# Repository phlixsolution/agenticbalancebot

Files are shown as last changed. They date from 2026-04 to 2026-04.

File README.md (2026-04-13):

# BalanceBot

A two-wheeled self-balancing robot (inverted pendulum) built on an **Arduino Nano 33 IoT** with a **Nano Motor Carrier**.

<p align="center">
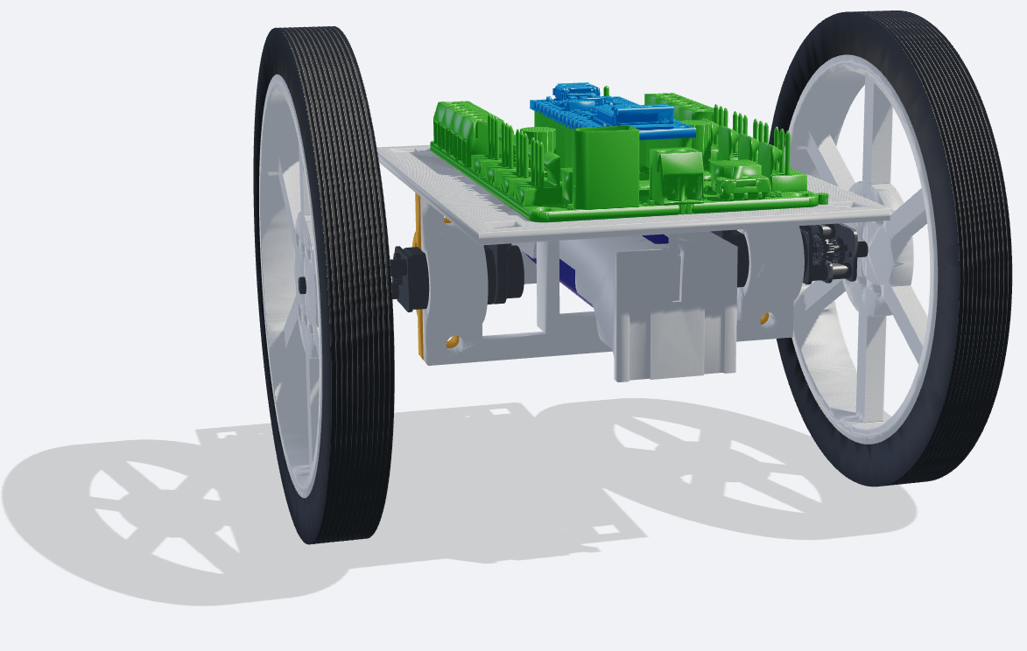
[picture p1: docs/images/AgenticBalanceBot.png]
BalanceBot CAD Assembly
  
</p>

The motivation behind this project is to develop a fully open-source robot from the existing components of the Arduino Engineering Kit Rev2. This allows interested owners of the kit to take the next step and gain a sustainable, license-independent engineering solution. Starting from these components, all necessary development steps and following design decisions are explained comprehensible in the documentation and provided in this repo. To keep the development effort manageable while leveraging the latest technology, [Agentic Supremacy](https://github.com/5omeOtherGuy/claude-skills-deploy) was developed and applied for this project.

The project follows a structured commissioning approach: each hardware subsystem is characterised and validated before the control loop is tuned.

## Hardware

| Component | Detail |
|---|---|
| MCU | Arduino Nano 33 IoT (SAMD21, WiFi/BLE) |
| Motor driver | Arduino Nano Motor Carrier |
| IMU | BNO055 (9-DOF, on-chip fusion) |
| Motors | 2 x micro gear motors, 100:1 ratio |
| Encoders | 2 x magnetic, 1200 counts/rev |
| Frame | Custom design (FreeCAD) |

## Repository layout

```
Balancebot_code/
  src/balance/          Modular firmware (active development)
  src/balance.cpp       balance_v1 — monolithic reference (read-only)
  src/tests/            Test sketches (carrier_timing, imu_latency, deadzone_id)
  python/               acquire → process → analyze data pipeline
  docs/                 commissioning_plan, sign_conventions, system_model
  messungen/            Measurement data (results tracked in repo)

CAD_BalanceBot/         FreeCAD assembly, STEP files, CoM analysis

docs/adr/               Architecture Decision Records (ADR-0001 … 0007)
Knowledg/               Physics derivations and explanations
```

## Firmware environments

Built with [PlatformIO](https://platformio.org/). Each environment compiles a different firmware:

| Environment | Purpose |
|---|---|
| `balance` | Modular control loop (active development) |
| `balance_v1` | Original monolithic firmware (reference) |
| `carrier_timing` | I2C timing characterisation |
| `imu_latency` | BNO055 read latency measurement |
| `deadzone_id` | Motor deadzone identification |

```bash
pio run -e balance -t upload     # flash
pio device monitor               # serial monitor
```

## Data pipeline

A three-stage Python pipeline for measurement acquisition and analysis:

```bash
python python/acquire.py                    # record serial data
python python/process.py <raw_file.csv>     # validate and compute derived signals
python python/analyze.py <proc_file.csv>    # generate plots
```

## Commissioning phases

The robot is brought up in phases — each phase validates assumptions the next one depends on. See [`commissioning_plan.md`](Balancebot_code/docs/commissioning_plan.md) for details.

| Phase | Goal | Status |
|---|---|---|
| 0 | Hardware verification | pending |
| 1 | Motor Carrier I2C timing | pending |
| 2 | BNO055 mode decision | pending |
| 3 | Deadzone identification | pending |
| 4 | Centre-of-gravity measurement | pending |
| 5 | System model | pending |
| 6 | First balance attempt (PD) | pending |
| 7 | Position controller | pending |

## Key design decisions

Documented as [Architecture Decision Records](docs/adr/README.md):

- **ADR-0001** Modular firmware layout supersedes balance_v1
- **ADR-0003** Motor duty hard-capped at 45 % (driver current limit)
- **ADR-0004** Three-stage Python pipeline supersedes standalone scripts
- **ADR-0005** PlatformIO as build system
- **ADR-0006** Control loop fixed at 10 ms (100 Hz)

## Getting started

### Prerequisites

- [PlatformIO CLI](https://docs.platformio.org/en/latest/core/installation.html)
- Python 3.12+ with dependencies: `pip install -r Balancebot_code/python/requirements.txt`
- Arduino Nano 33 IoT connected via USB

### Build and flash

```bash
cd Balancebot_code
pio run -e balance -t upload
```

### Lint

```bash
make lint    # runs ruff on the Python pipeline
```

## License

This project is developed as a university/hobby project. No license has been chosen yet.

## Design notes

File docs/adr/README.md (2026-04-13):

# Architecture Decision Records

Decisions that shape this project, captured as they happen.
New ADRs go in `docs/adr/NNNN-slug.md` and are indexed here.

| ADR | Title | Status | Date |
|-----|---|---|---|
| [0001](0001-modular-firmware-layout.md) | Modular firmware layout supersedes balance_v1 | accepted | 2026-04-13 |
| [0002](0002-messungen-storage-split.md) | Measurement data split between NextCloud and git | accepted | 2026-04-13 |
| [0003](0003-max-duty-45-percent.md) | Motor duty cycle hard-capped at 45% | accepted | 2026-04-13 |
| [0004](0004-three-stage-python-pipeline.md) | Three-stage Python pipeline supersedes standalone scripts | accepted | 2026-04-13 |
| [0005](0005-platformio-build-system.md) | PlatformIO as the build and upload system | accepted | 2026-04-13 |
| [0006](0006-control-loop-period-10ms.md) | Control loop period fixed at 10 ms (100 Hz) | accepted | 2026-04-13 |
| [0007](0007-ruff-python-linter.md) | ruff as the Python linter for the data pipeline | accepted | 2026-04-13 |

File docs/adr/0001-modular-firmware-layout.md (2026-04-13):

---
id: 0001
title: Modular firmware layout supersedes balance_v1
status: accepted
date: 2026-04-13
deciders: [both collaborators]
tags: [firmware, architecture]
---

# ADR-0001: Modular firmware layout supersedes balance_v1

## Context

The first working firmware, `Balancebot_code/src/balance.cpp` ("balance_v1"), is a
single 156-line file containing IMU setup, motor control, PID math, serial
logging, and the main loop. It proved the hardware works: the BNO055 reads,
the Motor Carrier drives, encoders count, and a basic PID compiles and runs.

As we move from "does anything work" to the commissioning phases in
`docs/commissioning_plan.md`, several limits of the monolithic file started
to hurt:

- **No unit boundaries.** Phase 3 (deadzone identification) and Phase 6
  (first balance attempt) need to swap controllers and log formats without
  touching IMU or motor code. In v1 every change touches the same file.
- **No test sketches can share code.** `src/tests/` (carrier_timing,
  imu_latency, deadzone_id) would either duplicate v1's driver code or
  include the whole file. Neither is acceptable.
- **Hardware-critical parameters are scattered.** `MAX_DUTY`,
  `DEADZONE_DUTY`, `FALLEN_ANGLE_DEG`, and the PID gains need one canonical
  location so CLAUDE.md's "ask before changing" list maps to real lines.
- **No explicit state machine.** v1 is always running; there is no IDLE,
  no FALLEN recovery, no E-STOP. For Phase 6+ with the wheels on the ground
  this is unsafe.

Alternatives considered:

1. **Keep extending `balance.cpp`.** Rejected — every added concern makes
   the next change harder, and the tuning phases will add many concerns.
2. **Rewrite as a single new monolithic file.** Rejected — same problem,
   just with newer code.
3. **Split into modules with a state machine and a central config header.**
   Chosen.

## Decision

`Balancebot_code/src/balance/` is the active firmware. It is organized as:

| Module | Responsibility |
|---|---|
| `config.h` | All hardware-critical constants (single source of truth) |
| `imu.{h,cpp}` | BNO055 init, read, angle extraction |
| `motor.{h,cpp}` | Motor Carrier wrapper, duty clamping, deadzone compensation |
| `encoder.{h,cpp}` | Encoder read and position tracking |
| `pid.{h,cpp}` | PID with anti-windup |
| `logger.{h,cpp}` | CSV serial output |
| `state_machine.h` | States INIT → CALIBRATING → IDLE → BALANCING → FALLEN → E_STOP, plus transition logic. Header-only (no `.cpp`) since it is enums + inline helpers. |
| `main.cpp` | Setup, loop, serial command dispatch |

`balance.cpp` (v1) and `src/*.cpp.bak` files are **frozen reference
artifacts**. They are kept in the repo but not edited. CLAUDE.md's
"What not to touch" section enforces this.

New work — deadzone compensation, cascade controllers, tuning logging —
lands in `src/balance/` only.

## Consequences

**Positive**
- Test sketches in `src/tests/` can `#include` individual modules instead
  of duplicating driver code.
- The state machine makes safety transitions (FALLEN cutoff, E-STOP)
  explicit and reviewable.
- `config.h` gives CLAUDE.md's parameter table exact line references,
  so "ask before changing" is enforceable in review.
- Per-module files stay small enough to review as units (largest is
  `main.cpp` at ~294 lines).

**Negative**
- Two firmware trees coexist. A reader unfamiliar with the history might
  start from `balance.cpp` by accident. Mitigated by CLAUDE.md and by this
  ADR.
- Slightly more boilerplate (headers, includes) than a single file.

**Neutral**
- v1's serial log format (`millis,pitch,p,i,d,pid_out,duty,position`) is
  preserved by `logger.cpp` so existing `messungen/` recordings remain
  comparable.

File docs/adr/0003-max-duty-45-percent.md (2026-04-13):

---
id: 0003
title: Motor duty cycle hard-capped at 45%
status: accepted
date: 2026-04-13
deciders: [both collaborators]
tags: [firmware, hardware, safety]
---

# ADR-0003: Motor duty cycle hard-capped at 45%

## Context

The Arduino Motor Carrier's motor driver is rated for a continuous current
of **500 mA**. Measured stall current of the motors is **1.03 A** (see
`config.h` line 48: `// Motorstall: 1.03 A, Treibergrenze: 0.50 A`).

At 100% PWM duty the motors can draw their full stall current, which is
roughly 2× the driver's rating. Sustained overcurrent destroys the driver.

The PID output is unbounded by design (integral wind-up and large angle
errors can push it well above 100). Without a hard cap in the motor layer,
a transient or tuning mistake passes a destructive command directly to the
hardware.

The cap must be set low enough to keep current within the driver rating
under worst-case (stall) conditions, while leaving enough authority for
the balance controller to be effective.

At 45% duty and the measured stall current of 1.03 A:

```
I_stall_at_45% ≈ 0.45 × 1.03 A ≈ 0.46 A  <  0.50 A rated
```

This gives a small but real margin without requiring a precise motor
characterization.

## Decision

`MAX_DUTY = 45` in `config.h`. The motor layer clamps every duty command
to `[-MAX_DUTY, +MAX_DUTY]` before writing to the Motor Carrier.

This value must not be raised without either:
- measuring that the chosen duty does not produce sustained overcurrent, or
- replacing the motor driver with one rated for higher current.

## Consequences

**Positive**
- Driver is protected during all commissioning phases, including Phase 6
  where large PID transients are expected during the first balance attempts.
- A tuning mistake that saturates the PID output does not damage hardware.

**Negative**
- Limits peak torque and top speed. If the balance controller requires
  more authority (e.g. recovering from a large disturbance), 45% may be
  insufficient. This will become apparent during Phase 6 testing.
- If the motors are lightly loaded (wheels off ground), 45% may still
  produce audible coil whine or thermal stress at sustained stall — the cap
  does not replace the stall-detection timeout (`STALL_TIMEOUT_MS`).

**Neutral**
- `DEADZONE_DUTY = 10` (Phase 3 estimate) sits well below `MAX_DUTY`.
  The effective command range for balancing is therefore [10, 45]% in
  each direction, shrunk further by whatever deadzone compensation is
  added after Phase 3.

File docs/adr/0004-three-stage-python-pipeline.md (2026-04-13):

---
id: 0004
title: Three-stage Python pipeline supersedes standalone scripts
status: accepted
date: 2026-04-13
deciders: [both collaborators]
tags: [tooling, data, python]
---

# ADR-0004: Three-stage Python pipeline supersedes standalone scripts

## Context

The repository contains several older Python scripts that grew up
alongside the early hardware experiments:

```
python/serial_to_csv.py     — recorded serial data to a CSV
python/plot_serial.py       — plotted live data from the serial port
python/plot_csv.py          — plotted a previously saved CSV
python/plot_pid_live.py     — plotted PID signals live
python/plot_sensor_live.py  — plotted sensor signals live
```

Each script was self-contained: it handled its own serial reading,
its own CSV parsing, and its own plotting in a single file. That was
fine for early exploration, but as the commissioning phases grew more
systematic, three problems emerged:

1. **No reuse between scripts.** If the serial column format changed,
   every script needed updating independently. There was no shared
   definition of "what a valid balance CSV looks like."

2. **No way to re-run one step.** To replot with different axis ranges
   you had to re-run the whole script — including re-reading the serial
   port if the data wasn't already saved, or re-parsing and re-computing
   everything if it was.

3. **No validation layer.** Raw serial data can contain partial lines,
   glitches, and timing noise. None of the old scripts had a dedicated
   step that checked the data before plotting it. Bad rows silently
   produced bad plots.

## Decision

The active pipeline is `acquire.py → process.py → analyze.py`.
Each stage has one job and a clear input/output contract:

| Stage | Input | Output | Job |
|---|---|---|---|
| `acquire.py` | Serial port | `messungen/raw/*.csv` | Read from the robot, write raw data, nothing else |
| `process.py` | raw CSV | `messungen/processed/*_proc.csv` | Validate rows, compute derived signals (dt, t_s, speed_rad_s, pos_diff, pid_out) |
| `analyze.py` | processed CSV | `messungen/plots/*.png` | Plot — pitch, PID components, duty, position, deadzone curves |

Shared constants (serial port, baud rate, column names, directory paths)
live in `config.py` so each stage reads the same definitions.

The old standalone scripts are **frozen**. They are kept in the repo for
reference but must not be extended. New measurement work uses the pipeline.

### Why this split matters

Because the stages are separate programs with files as the handoff,
each one can be re-run independently:

- **Re-process** an old raw recording with a fixed `process.py` (e.g.
  after correcting a unit conversion) without re-recording.
- **Re-plot** with different parameters without re-processing.
- **Validate** data once in `process.py`; `analyze.py` can trust its input.
- **Test sketches** (`carrier_timing`, `imu_latency`, `deadzone_id`)
  use `acquire.py` with a `--mode` flag — no need for separate recording
  scripts per test type.

## Consequences

**Positive**
- Column names, directory paths, and validation rules are defined once
  in `config.py` and imported by all three stages.
- A change to the serial log format (e.g. adding a new signal) means
  updating `config.py` and `process.py` only — `analyze.py` receives
  the new column in the processed CSV automatically.
- The directory split in ADR-0002 (`raw/`, `processed/`, `plots/`) maps
  directly to the three stages. The two decisions reinforce each other.

**Negative**
- Three commands instead of one. For a quick look at live data, the old
  `plot_serial.py` was faster to invoke. `analyze.py --live` partially
  addresses this but is a secondary use case.
- The old scripts are still present in `python/`, which can confuse a
  new reader. Mitigated by this ADR and by CLAUDE.md's "What not to
  touch" section.

**Neutral**
- `process.py` currently computes a fixed set of derived signals. When
  new commissioning phases require new quantities (e.g. frequency-domain
  analysis for Phase 5), they are added to `process.py` as new columns
  — the pipeline structure does not need to change.

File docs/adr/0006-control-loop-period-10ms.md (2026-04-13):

---
id: 0006
title: Control loop period fixed at 10 ms (100 Hz)
status: accepted
date: 2026-04-13
deciders: [both collaborators]
tags: [firmware, control]
---

# ADR-0006: Control loop period fixed at 10 ms (100 Hz)

## Context

A self-balancing robot is an *inverted pendulum* — an inherently unstable
system that will fall over unless the controller corrects it fast enough.
"Fast enough" is determined by the physics: the natural falling speed of
the pendulum sets a minimum update rate below which no controller can
recover it.

Two hardware constraints bound the choice from above and below:

**Lower bound — physics and sensor bandwidth.**
A typical two-wheeled balancing robot with a centre-of-gravity height of
a few centimetres has a natural frequency in the range of a few Hz. The
controller must run significantly faster than the falling dynamics —
conventionally at least 10× the natural frequency — to have enough time
to react. 50–100 Hz is the standard range for robots of this size.

**Upper bound — IMU read time.**
The BNO055 IMU is read over I²C on every loop iteration. The `imu_latency`
test sketch (`src/tests/imu_latency/`) exists specifically to measure how
long a `getEvent()` call takes on this hardware. Early characterisation
showed the read takes roughly 2–3 ms. At a 5 ms period (200 Hz) the IMU
read alone would consume 40–60% of the budget; any overrun makes the loop
non-deterministic. The Arduino Nano 33 IoT also runs serial command
parsing, encoder updates, PID computation, and state machine transitions
in the same loop body.

Going below 10 ms risks overrunning the IMU read time, which was noted
explicitly in `config.h`:

```cpp
// 10 ms = 100 Hz. Nicht unter 10 ms gehen (Bandbreite des inversen Pendels)
constexpr unsigned long LOOP_PERIOD_MS = 10;
```

## Decision

`LOOP_PERIOD_MS = 10` (100 Hz). The loop uses a `millis()`-based
non-blocking scheduling pattern — if less than 10 ms has elapsed since
the last iteration, `loop()` returns immediately:

```cpp
if (elapsedMs < LOOP_PERIOD_MS) return;
float dt = (float)elapsedMs / 1000.0f;
```

`dt` is measured from actual elapsed time rather than the nominal 10 ms,
so small jitter in the Arduino's task scheduling does not accumulate as
a timing error in the PID integrator.

Timer interrupts were not used. The `millis()` pattern is simpler,
sufficient for this application, and avoids the complexity of interrupt
safety around shared state (IMU object, PID state, encoder counts).

## Consequences

**Positive**
- 10 ms leaves ~7–8 ms headroom after the IMU read for all other
  loop work — PID, encoder, serial, state machine.
- `dt` from actual elapsed time makes the PID integrator correct even
  if occasional loop iterations run slightly long.
- Simple to understand and debug: no interrupt handlers, no shared
  state concerns.

**Negative**
- `millis()` scheduling is cooperative, not preemptive. A blocking call
  anywhere in the loop (e.g. a slow I²C transaction) delays the next
  iteration. This is why all loop work must be non-blocking.
- 100 Hz may prove insufficient if the CoG height measurement (Phase 4)
  reveals a faster natural frequency than expected. In that case
  `LOOP_PERIOD_MS` can be lowered, but only after re-running
  `imu_latency` to confirm the new period is safe.

**Neutral**
- The `imu_latency` test sketch exists specifically to validate the upper
  bound assumption. It must be re-run before any change to `LOOP_PERIOD_MS`.

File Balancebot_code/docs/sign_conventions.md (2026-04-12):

# BalanceBot -- Vorzeichen-Konventionen

**Status:** Aus Diagnose-Sketch verifiziert (diagnose.cpp.bak)

---

## Koordinatensystem

Der Bot steht auf dem Boden, Fahrtrichtung ist "vorwärts" (definiert als Richtung, in die der USB-Port zeigt).

```
         ^ oben (Kippachse: positives Pitch = kippt nach hinten)
         |
    _____________________
   |                     |
   |   [USB]  [Motor C.] |  <-- Rückseite
   |_____________________|
         |
    === Achse ===
    (Wheel L)  (Wheel R)
         |
      Fahrtrichtung VORWÄRTS -->
```

---

## IMU (BNO055) -- Euler-Winkel

| Achse | event.orientation.x | Bedeutung |
|---|---|---|
| x | Heading [°] | Kompass-Nord (nicht genutzt) |
| y | Roll [°] | Seitwärtskippen |
| **z** | **Pitch [°]** | **Vorwärts/Rückwärts-Kippen** |

**Vorzeichenkonvention Pitch:**
- `pitch = 0°` → Bot steht aufrecht
- `pitch < 0°` → Bot kippt **vorwärts** (USB-Seite neigt sich nach vorne)
- `pitch > 0°` → Bot kippt **rückwärts**

*Verifiziert durch: Manuelles Kippen des Bots, Beobachtung des Serial-Outputs.*

---

## Motoren (M1 / M2)

| Motor | Lage | Positive Duty-Richtung |
|---|---|---|
| M1 | Rechts (Fahrtrichtung) | dreht **rückwärts** (wegen Einbaulage gespiegelt) |
| M2 | Links | dreht **vorwärts** |

**Ansteuerung für Vorwärtsfahrt:**
```
Vorwärts:  M1.setDuty(-duty)  +  M2.setDuty(+duty)   // duty > 0
Rückwärts: M1.setDuty(+duty)  +  M2.setDuty(-duty)   // duty > 0
```

In `motor.cpp` (`_applyToMotors`):
```cpp
m1Duty = -duty;   // invertiert wegen Einbaulage
m2Duty = +duty;
```

---

## Encoder

| Encoder | Motor | Vorwärtsfahrt |
|---|---|---|
| encoder1 | M1 (rechts) | **negativer** Count |
| encoder2 | M2 (links)  | **positiver** Count |

**Positions-Berechnung (Geradeausfahrt):**
```
position = (encoder2.getRawCount() - encoder1.getRawCount()) / 2
```
- Formel hebt die gegenläufige Montage auf
- Positiver Wert = Vorwärtsfahrt ✓

*Auflösung: 1200 Counts / Umdrehung → 0.236 mm / Count*

---

## Regelkreis -- Vorzeichen-Überprüfung

**KRITISCH:** Falsches Vorzeichen = instabiler Regelkreis (beschleunigt in Absturzrichtung)

Checkliste vor dem ersten Balancierversuch:

1. Bot nach **vorne** kippen → `pitch` wird **negativ** ✓/✗
2. Positiver Duty → Motor M2 dreht **vorwärts**, M1 dreht **rückwärts** ✓/✗
3. Bot nach vorne kippen → Regler berechnet **positiven** Fehler (`0 - negative_pitch > 0`) ✓/✗
4. Positiver Fehler → positiver PID-Ausgang → positive Duty → Bot fährt **vorwärts** ✓/✗
5. Vorwärtsfahren bei vorwärts-Kippen **stabilisiert** den Bot ✓/✗

**Negativer Feedback-Loop muss gelten:**
```
Vorwärts-Kippen → Fehler positiv → Duty positiv → vorwärts fahren → Kippen wird reduziert
```

Wenn der Bot beim Start sofort wegfährt: Vorzeichen von Kp umkehren!

---

## Zusammenfassung für Copy-Paste

```
pitch (event.orientation.z):  0=aufrecht, negativ=vorwärts-Kippen
Motor-Ansteuerung:             Vorwärts = M1(-), M2(+)
Encoder:                       Vorwärts = Enc1↓, Enc2↑
Position:                      (Enc2 - Enc1) / 2, positiv=vorwärts
PID-Fehler:                    setpoint(0) - pitch
Regelung:                      Fehler>0 → Duty>0 → vorwärts (korrigiert ✓)
```

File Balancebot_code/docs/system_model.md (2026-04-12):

# BalanceBot -- Systemmodell (Inverses Pendel auf Rädern)

**Status:** Platzhalter -- wird nach CoG-Messung (Phase 4) ausgefüllt

**Referenz:** Grasser et al. 2002, "JOE: A Mobile, Inverted Pendulum"

---

## Zustandsvektor

```
x = [θ, θ̇, x_pos, ẋ]
     │   │   │      └── Fahrgeschwindigkeit [m/s]
     │   │   └───────── Fahrposition [m]
     │   └───────────── Kippwinkelgeschwindigkeit [rad/s]
     └───────────────── Kippwinkel [rad] (0 = aufrecht)
```

---

## Systemparameter (aus Datenblatt / Messung)

| Symbol | Bedeutung | Wert | Quelle |
|---|---|---|---|
| m | Gesamtmasse [kg] | 0.204 | Gewogen |
| r | Radradius [m] | 0.045 | CAD |
| L | CoG-Höhe über Achse [m] | **TODO: Messen!** | Knife-Edge |
| J_w | Trägheit Rad [kg·m²] | TODO | Abschätzung |
| J_b | Trägheit Körper [kg·m²] | TODO | Abschätzung |
| R_a | Ankerwiderstand [Ω] | ≈ 11.65 | Datenblatt* |
| K_t | Drehmomentkonstante [N·m/A] | ≈ 0.2115 | Datenblatt* |
| K_e | Gegen-EMK-Konstante [V·s/rad] | = K_t | (BLDC-Näherung) |
| n | Getriebeübersetzung [-] | 100 | Datenblatt |

*Abschätzung aus Stallmoment und Stallstrom:  
  Kt = Stallmoment / (Stallstrom × n) = 0.0222 N·m / (1.03 A × 100) ≈ 0.000215 N·m/A (Motor)  
  Nach Getriebe: Kt_eff = Kt × n = 0.0215 N·m/A (Abtrieb)

*Ankerwiderstand: Ra = Nennspannung / Stallstrom = 12 V / 1.03 A ≈ 11.65 Ω

---

## Linearisiertes Zustandsraummodell

```
ẋ = A·x + B·u
y = C·x
```

Eingang: `u` = normierter Duty-Wert [-1, +1] (wird intern auf Spannung umgerechnet)  
Ausgang: `y` = [θ, x_pos] (IMU + Encoder)

Die A- und B-Matrizen werden nach Messung von L berechnet.

**TODO:** Python-Skript `python/system_id.py` erstellen:
1. Parameter eintragen
2. A, B aufstellen
3. Eigenwerte berechnen (offener Kreis: ein instabiler Pol erwartet!)
4. Steuerbarkeit prüfen: `control.ctrb(A, B)`
5. LQR-Design: `K, S, E = control.lqr(A, B, Q, R)`

---

## Natürliche Frequenz (Abschätzung)

Mit L ≈ 0.025 m (Schätzwert):

```
ω_n = sqrt(g / L) = sqrt(9.81 / 0.025) ≈ 19.8 rad/s ≈ 3.15 Hz
```

**Folgerung:** Controller-Bandbreite muss ≥ 3 × ω_n ≈ 10 Hz sein.  
Bei 100 Hz Abtastrate: 10 Samples pro Pendel-Schwingung → knapp ausreichend.  
→ **Abtastrate nicht unter 100 Hz reduzieren!**

---

## Nächste Schritte

- [ ] CoG-Höhe L messen (Knife-Edge-Test, siehe commissioning_plan.md Phase 4)
- [ ] Trägheitsmomente J_w und J_b abschätzen oder messen
- [ ] `python/system_id.py` schreiben
- [ ] LQR- oder Kaskadenregler-Entwurf durchführen
- [ ] Regler in `src/balance/main.cpp` einbauen

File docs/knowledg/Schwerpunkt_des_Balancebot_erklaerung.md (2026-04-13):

# Schwerpunkt (Center of Mass) — Bedeutung und Messmethoden

## Warum ist der Schwerpunkt so wichtig?

Der BalanceBot ist ein **inverses Pendel** — ein Stab, der auf seiner Spitze balanciert. Die Physik dahinter:

### 1. Kippmoment und Reaktionszeit

Je **hoeher** der CoM ueber der Radachse liegt, desto **langsamer** kippt der Bot. Das klingt paradox, ist aber das gleiche Prinzip wie beim Besenstiel-Balancieren: ein langer Stiel ist leichter zu balancieren als ein kurzer.

Physikalisch: Die Winkelfrequenz des inversen Pendels ist

```
omega_0 = sqrt(m * g * h / J)
```

| Symbol | Beschreibung | Einheit |
|---|---|---|
| omega_0 | Eigenfrequenz des inversen Pendels | rad/s |
| m | Gesamtmasse des Bots | kg |
| g | Erdbeschleunigung (9.81) | m/s^2 |
| h | Abstand CoM zur Radachse (vertikal) | m |
| J | Traegheitsmoment um die Radachse | kg*m^2 |

Ein hoeherer CoM erhoeht `h`, aber `J` waechst mit `h^2` — netto wird das System **traeger** und damit einfacher zu regeln.

#### Herleitung von omega_0

**Schritt 1 — Drehmoment durch Gravitation:**

Wenn der Bot um einen kleinen Winkel θ aus der Vertikalen kippt, erzeugt die Schwerkraft ein Drehmoment um die Radachse:

```
tau = m * g * h * sin(theta)
```

| Symbol | Beschreibung | Einheit |
|---|---|---|
| tau | Drehmoment um die Radachse | N*m |
| m | Gesamtmasse des Bots | kg |
| g | Erdbeschleunigung (9.81) | m/s^2 |
| h | Abstand CoM zur Radachse | m |
| theta | Kippwinkel aus der Vertikalen | rad |

**Schritt 2 — Newtons Rotationsgesetz:**

```
J * theta_ddot = tau
```

| Symbol | Beschreibung | Einheit |
|---|---|---|
| J | Traegheitsmoment um die Radachse | kg*m^2 |
| theta_ddot | Winkelbeschleunigung | rad/s^2 |
| tau | Drehmoment um die Radachse | N*m |

Eingesetzt:

```
J * theta_ddot = m * g * h * sin(theta)
```

**Schritt 3 — Linearisierung fuer kleine Winkel** (`sin(theta) ≈ theta`):

```
J * theta_ddot = m * g * h * theta
```

Umgestellt:

```
theta_ddot = (m * g * h / J) * theta
```

Das ist eine Differentialgleichung der Form `theta_ddot = omega_0^2 * theta`, mit:

```
omega_0 = sqrt(m * g * h / J)
```

> **Vorzeichen-Hinweis:** Beim *normalen* Pendel (CoM unter der Achse) steht ein Minus: `theta_ddot = -omega_0^2 * theta` → harmonische Schwingung, stabil. Beim *inversen* Pendel (CoM ueber der Achse) ist das Vorzeichen positiv → exponentielles Wachstum, instabil. Genau deshalb braucht der BalanceBot einen aktiven Regler.

#### Warum waechst J mit h²? — Steiner'scher Satz

Jeder Koerper hat ein Traegheitsmoment `J_cm` um seinen eigenen Schwerpunkt. Wird die Drehachse um eine Strecke `h` vom Schwerpunkt weg verschoben (hier: zur Radachse), gilt der **Steiner'sche Satz** (parallel axis theorem):

```
J = J_cm + m * h^2
```

| Symbol | Beschreibung | Einheit |
|---|---|---|
| J | Traegheitsmoment um die Radachse | kg*m^2 |
| J_cm | Traegheitsmoment um den eigenen Schwerpunkt | kg*m^2 |
| m | Gesamtmasse des Bots | kg |
| h | Abstand Schwerpunkt zur Radachse | m |

Der Term `m * h^2` waechst **quadratisch** mit dem Abstand `h`.

**Einsetzen in omega_0:**

```
omega_0 = sqrt(m * g * h / (J_cm + m * h^2))
```

Fuer den Fall, dass der Bot naeherungsweise eine Punktmasse im Abstand `h` ist (`J_cm` vernachlaessigbar klein gegenueber `m * h^2`):

```
omega_0 ≈ sqrt(m * g * h / (m * h^2))
         = sqrt(g / h)
```

**Zentrales Ergebnis:**

```
omega_0 ≈ sqrt(g / h)
```

- `h` verdoppeln → omega_0 sinkt um Faktor sqrt(2) → Bot kippt **langsamer**
- `h` halbieren → omega_0 steigt um Faktor sqrt(2) → Bot kippt **schneller**

Deshalb ist ein hoher Schwerpunkt einfacher zu balancieren — genau wie ein langer Besenstiel vs. ein kurzer Bleistift.

### 2. Y-Offset (vor/hinter der Achse)

Wenn der CoM nicht genau ueber der Radachse sitzt, muss der Regler **permanent gegensteuern**, um das statische Kippmoment auszugleichen. Das kostet Energie und reduziert den nutzbaren Regelbereich. Ideal: `CoM_Y = 0`.

### 3. X-Offset (links/rechts)

Ein seitlicher Versatz erzeugt eine **Kurvenfahrt-Tendenz** — der Bot driftet zur schweren Seite. Ideal: `CoM_X = 0`.

### 4. Regelparameter haengen direkt vom CoM ab

Die PID-Gains (`KP_ANGLE`, `KD_ANGLE` in `config.h`) werden auf Basis des Systemmodells berechnet. Das Modell braucht `COG_HEIGHT_M` — den Abstand des CoM zur Radachse. Ein falscher Wert fuehrt zu:

- Zu aggressive Gains -> Oszillation
- Zu schwache Gains -> Bot kippt um

---

## Messmethoden

### Methode 1: CAD-Berechnung (was `com_analysis.py` macht)

Das Skript berechnet den CoM aus den Volumina und Materialdichten aller Teile. Jedem Teil wird eine Materialdichte zugewiesen:

| Material | Dichte [g/cm^3] |
|---|---|
| PLA (Rahmen, Motorhalter, Radnaben) | 1.04 |
| FR4 / PCB (Motor Carrier, Arduino) | 1.85 |
| Batterie (18650 Li-Ion) | 2.70 - 2.75 |
| N20-Motor mit Getriebe | 4.50 |
| Radreifen (Gummi/TPU) | 1.15 |

**Vorteil:** Schnell, iterativ anpassbar, keine Hardware noetig.
**Nachteil:** Nur so genau wie die CAD-Modelle und die angenommenen Dichten.

Ausfuehrung:

```bash
cat com_analysis.py | /snap/bin/freecad --console
```

---

### Methode 2: Knife-Edge-Test (empfohlen zur Validierung)

Dies ist die in `commissioning_plan.md` Phase 4 vorgesehene Methode.

1. Bot komplett aufbauen (alle Teile montiert, Akku eingesetzt)
2. Den Bot auf eine **scharfe Kante** (Lineal, Metallschiene) legen
3. Die Kante verschieben, bis der Bot **genau im Gleichgewicht** liegt
4. Den Abstand der Kante zur Radachse messen -> das ist `h` (CoG height)
5. In **zwei Achsen** wiederholen (Y und X), um den vollstaendigen CoM zu bestimmen

```
        +----------+
        | BalanceBot|
        |    x CoM |
        +----+-----+
             |
    =========+=========  <- Knife edge (Gleichgewichtspunkt)
             |
         ----o----       <- Radachse
```

**Vorteil:** Einfach, keine Spezialgeraete noetig.
**Nachteil:** Nur eine Achse pro Messung.

---

### Methode 3: Aufhaenge-Methode (Plumb-Line)

1. An zwei verschiedenen Stellen am Bot je einen Haken oder Faden befestigen (nicht an der Achse)
2. Bot am ersten Punkt aufhaengen, frei pendeln lassen
3. Lotlinie entlang des Fadens auf dem Bot markieren
4. Bot am zweiten Punkt aufhaengen, erneut Lotlinie markieren
5. **Schnittpunkt der beiden Linien = CoM**
6. Vertikalen Abstand vom Schnittpunkt zur Radachse messen

**Vorteil:** Bestimmt den CoM in zwei Dimensionen gleichzeitig.
**Nachteil:** Markierungen muessen praezise sein.

---

### Methode 4: Zwei-Waagen-Methode (Two-Scale)

Den Bot flach auf zwei identische Kuechenwaagen legen, die in bekanntem Abstand stehen:

```
Waage A (zeigt F_A)         Waage B (zeigt F_B)
    |___________________________|
    <------- d_gesamt --------->
```

Berechnung:

```
L_cog_von_A = (F_B * d_gesamt) / (F_A + F_B)
```

| Symbol | Beschreibung | Einheit |
|---|---|---|
| L_cog_von_A | Abstand des CoM von Waage A | m |
| F_A | Gewichtskraft auf Waage A | N |
| F_B | Gewichtskraft auf Waage B | N |
| d_gesamt | Abstand zwischen den beiden Waagen | m |

Dies ergibt die horizontale CoM-Position. Den Bot 90 Grad drehen (aufrecht abstuetzen) und wiederholen, um die **vertikale CoM-Hoehe** zu bestimmen.

**Vorteil:** Rechnerisch genau, reproduzierbar.
**Nachteil:** Aufwendiger Aufbau, Bot muss stabil positioniert werden.

---

## Empfohlenes Vorgehen fuer den BalanceBot

1. **CAD-Berechnung** mit `com_analysis.py` -> erste Abschaetzung
2. **Knife-Edge-Test** (Phase 4) -> Validierung am echten Bot
3. Gemessenen Wert als `COG_HEIGHT_M` in `config.h` eintragen
4. Erst dann mit PID-Tuning (Phase 6) beginnen

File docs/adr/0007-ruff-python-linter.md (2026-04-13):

---
id: 0007
title: ruff as the Python linter for the data pipeline
status: accepted
date: 2026-04-13
deciders: [both collaborators]
tags: [python, tooling]
---

# ADR-0007: ruff as the Python linter for the data pipeline

## Context

The data pipeline (`acquire.py`, `process.py`, `analyze.py`) is shared
between two collaborators. Without a linter, style inconsistencies and
common mistakes (unused imports, wrong import order, outdated syntax)
accumulate silently and make the code harder to read over time.

The Python ecosystem has several established linting tools:
- **flake8** — style and error checking, widely used but slow, requires
  separate plugins for import sorting and syntax modernisation
- **pylint** — thorough but very slow and verbose; typically overkill for
  a small focused codebase
- **black** — formatter only, does not catch logical errors or imports
- **ruff** — covers style errors, warnings, undefined names, import
  sorting (`isort`), and syntax modernisation (`pyupgrade`) in a single
  tool; written in Rust and runs in milliseconds

For a two-person project running linting manually before commits, speed
and simplicity matter more than exhaustive analysis. Maintaining separate
tools for formatting, import sorting, and error checking adds friction
without proportional benefit.

## Decision

**ruff** is configured in `Balancebot_code/pyproject.toml` with the
following rule sets:

| Rule set | What it checks |
|---|---|
| `E`, `W` | pycodestyle style errors and warnings |
| `F` | pyflakes — undefined names, unused imports |
| `I` | import order (replaces isort) |
| `UP` | outdated Python syntax (replaces pyupgrade) |

`E501` (line too long) is suppressed globally — matplotlib and pandas
call chains make strict line limits impractical without hurting
readability.

The superseded standalone scripts (`plot_serial.py`, `serial_to_csv.py`,
`plot_csv.py`, `plot_pid_live.py`, `plot_sensor_live.py`) are excluded
from linting entirely (`ALL`). They are frozen reference artifacts
(ADR-0004); generating lint noise from them would obscure real issues
in the active pipeline.

Line length is set to 100 characters — a pragmatic middle ground between
the traditional 79 (PEP 8) and the unconstrained style of the pipeline's
data manipulation chains.

## Consequences

**Positive**
- One tool replaces flake8 + isort + pyupgrade. A single `ruff check`
  invocation covers all rule sets in under a second.
- Excluding the frozen scripts means lint output is signal only — every
  reported issue is in code that is actively maintained.
- `pyproject.toml` pins the rule sets and line length, so both
  collaborators get identical results regardless of ruff version.

**Negative**
- ruff does not auto-fix all violations (though `ruff check --fix`
  handles most `I` and `UP` rules). Some style errors still require
  manual correction.

**Neutral**
- ruff is not run as a commit hook by default. The Makefile's `lint`
  target (`make lint`) is the intended invocation point. Adding a
  pre-commit hook is possible but not required for a two-person project.

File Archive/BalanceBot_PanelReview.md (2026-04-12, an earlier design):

# Panel Review: BalanceBot
*Generated: 2026-04-10 | Reviewers: data-analyst, embedded-dev, engineer*

**Overall Verdict: NEEDS IMPROVEMENT**

The hardware is adequate and the toolchain is functional, but the project lacks the control engineering backbone (plant model, state definition, control architecture, safety strategy) needed before attempting closed-loop balancing. The motor driver current limit is a real but manageable constraint.

---

## Consensus

All three reviewers agree on the following:

- **The stall current / driver limit mismatch (1.03A vs. 500mA) must be addressed in software before any closed-loop balance attempt.** A duty cycle clamp at ~48% is the minimum viable protection. All three independently derived this figure.
- **No plant model exists yet — this blocks all principled controller design.** Trial-and-error tuning on this system risks repeated overcurrent events and driver damage.
- **Sign/coordinate conventions are undefined.** A single sign error inverts the feedback loop and the robot accelerates into the ground. This must be documented and verified before writing any control code.
- **IMU data is not logged.** The primary controlled variable (tilt angle) is absent from the CSV schema, making post-hoc analysis of balance behavior impossible.
- **Anti-windup is mandatory.** With the hard duty cap, integrator windup during saturation will cause slow reversal and falls. All three reviewers flagged this independently.
- **Sampling time jitter is uncharacterized.** No hardware timer drives the control loop — `loop()` with `millis()` checks produces jitter that can destabilize the controller.

---

## Domain-Specific Insights

### Data Analyst — Dead-time measurement before system identification

Before fitting any transfer function, the total loop delay (serial framing + task scheduling + filter group delay) must be measured. A 20-30ms unmodeled delay in a 10ms sampling system is not negligible and causes `curve_fit` to underestimate time constants. The fix: inject a known step, timestamp the command on the PC with `time.perf_counter()`, and measure the first non-zero response. Then fit a PT1+dead-time model.

### Embedded Developer — The ArduinoMotorCarrier library is a black box that must be characterized

Every control signal and sensor reading passes through I2C transactions to the ATSAMD11 co-processor. The latency, update rate, atomicity, and watchdog behavior of this communication path are unknown. A test sketch measuring round-trip times of `controller.ping()`, `encoder1.getRawCount()`, `M1.setDuty()`, and IMU reads (1000 iterations, log min/max/mean) is mandatory before trusting the library in a closed loop.

### Engineer — The system has ample torque margin but dynamic bandwidth is the real constraint

At the driver-limited torque (0.211 N·m total), the static torque margin is ~48:1 at 5° tilt — more than enough. The natural frequency of the inverted pendulum (with estimated L_cog = 25mm) is ~3.15 Hz, requiring a controller bandwidth of 10-15 Hz. At 100 Hz sampling, this gives only 7-10 samples per cycle — tight but workable. Do not reduce the sampling rate below 100 Hz.

---

## Critical Issues

| # | Issue | Raised by | Impact |
|---|---|---|---|
| 1 | **Motor stall current (1.03A) exceeds driver limit (500mA) — no software protection exists** | All three | Hardware damage or thermal shutdown during any significant balance correction. Duty clamp at 48% is mandatory. |
| 2 | **No hardware-timer-driven control loop** | Embedded, Engineer | Timing jitter from `loop()` + serial I/O + `controller.ping()` can destabilize the controller. 1-2ms jitter at 10ms sample = 10-20% variation. |
| 3 | **Motor Carrier communication path is uncharacterized** | Embedded | If `controller.ping()` or I2C transactions take 5ms on some calls, the 10ms budget is blown and the controller sees stale data. |

---

## Improvement Roadmap (unified)

| Priority | Improvement | Raised by | Actionable steps |
|---|---|---|---|
| **HIGH** | Implement duty limiting and stall detection | All three | `duty = constrain(duty, -48, +48)`. Add slew rate limit (max 20 units/sample). Stall detection: if `abs(duty) > 30 && abs(speed) < 5` for 500ms → E_STOP. |
| **HIGH** | Build linearized state-space model | Engineer, Data Analyst | Measure CoG height (knife-edge test). Extract motor params from datasheet (R_a ≈ 11.65Ω, K_t = 0.2115 N·m/A). Write the 4-state [θ, θ̇, x, ẋ] equations per Grasser et al. (2002). Verify open-loop eigenvalues. |
| **HIGH** | Characterize Motor Carrier communication | Embedded | Test sketch: 1000 iterations of each API call, log timing via `micros()`. Determine I2C bus speed, encoder atomicity, and `ping()` latency. |
| **HIGH** | Implement hardware-timer control loop | Embedded | Configure SAMD21 TC3 for 10ms ISR. Execute read→compute→actuate in the ISR or flag-driven highest-priority task. Verify with GPIO toggle. |
| **HIGH** | Add IMU data to log schema | Data Analyst, Embedded | Add `imu_angle_deg`, `imu_rate_dps` to the `Serial.println()` line. Cost: ~30 bytes/line at 100 Hz = 3 kB/s. |
| **HIGH** | Define and verify sign conventions | Engineer, Embedded | One-page diagram. Four test sketches: tilt forward → angle sign? Positive duty → encoder sign? Positive duty → wheel direction? Verify negative feedback loop product. |
| **HIGH** | Implement state machine | Embedded | States: INIT → CALIBRATING → IDLE → BALANCING → FALLEN → E_STOP. Transitions on tilt angle threshold, serial commands, overcurrent. Motors off in FALLEN and E_STOP. |
| **MEDIUM** | Implement anti-windup | Engineer, Data Analyst | Back-calculation: `e_aw = duty_clamped - duty_unclamped`, feed back to integrator with tracking gain `Kaw = 1/Ti`. |
| **MEDIUM** | Configure BNO055 for minimum latency | Engineer, Embedded | Set IMU mode (0x08), not NDOF. Disable magnetometer fusion. If latency still too high, implement complementary filter: `angle = 0.98*(angle + gyro*dt) + 0.02*accel_angle`. |
| **MEDIUM** | Split Python pipeline into acquire/process/analyze | Data Analyst | `acquire.py` (serial → raw CSV), `process.py` (validation + derived signals → Parquet), `analyze.py` (plots + fits). Add `config.py` and `requirements.txt`. |
| **MEDIUM** | Characterize and compensate motor dead zones | Engineer, Data Analyst | Ramp duty 0→100% slowly, log encoder velocity vs. duty. Implement piecewise linear feedforward per motor. |
| **MEDIUM** | Measure dead-time / transport delay | Data Analyst | Inject step from PC, timestamp with `time.perf_counter()`, measure first non-zero response. Fit PT1+dead-time model. |
| **MEDIUM** | Implement cascade control structure | Engineer | Inner loop: PD on tilt angle → duty. Outer loop: PI on position → tilt setpoint. Tune inner first (robot balances but drifts), then close outer. |
| **LOW** | Enable SAMD21 hardware watchdog | Embedded | WDT ~50ms timeout, fed only from control loop ISR. Catches I2C bus lockups. |
| **LOW** | Switch long-run storage to Parquet | Data Analyst | `df.to_parquet()` after validation. Keep raw CSV as archival input. |
| **LOW** | Report confidence intervals on all curve_fit results | Data Analyst | Compute `sigma = sqrt(diag(pcov))`, print 95% CI. Flag if CI width > 50% of nominal. |

---

## Research & Reference Projects

### Control Theory & Modeling

1. **Grasser, D'Arrigo, Colombi, Rufer — "JOE: A Mobile, Inverted Pendulum" (IEEE 2002)**
   Search: `Grasser D'Arrigo "JOE" inverted pendulum IEEE 2002`
   *Relevance:* The canonical reference for two-wheeled inverted pendulum state-space modeling. Provides the exact A and B matrices for BalanceBot's model.
   *What to look for:* State vector definition [θ, θ̇, x, ẋ], linearization procedure, LQR weight selection.

2. **Steve Brunton — Control Bootcamp (YouTube + GitHub)**
   Search: `Steve Brunton Control Bootcamp inverted pendulum`
   *Relevance:* LQR design for inverted pendulum with worked MATLAB examples. Directly applicable once the state-space model is built.
   *What to look for:* Controllability, LQR weight selection, observer design.

3. **Brian Douglas — Control Systems Lectures (YouTube / MATLAB Tech Talks)**
   Search: `Brian Douglas inverted pendulum state space`
   *Relevance:* Best video explanation of the complete state-space design flow from model to LQR to observer.
   *What to look for:* "What is LQR" and "What is a State Observer" videos.

4. **Franklin, Powell, Emami-Naeini — "Feedback Control of Dynamic Systems" (8th ed.)**
   *Relevance:* Chapter 7, Example 7.28 covers inverted pendulum LQR with explicit Q/R selection procedure.
   *What to look for:* Constraint-aware LQR weight tuning (R chosen so gains stay within actuator limits).

### Balancing Robot Implementations

5. **Brokking.net / YABR (Yet Another Balancing Robot)**
   URL: `http://www.brokking.net/yabr.html`
   *Relevance:* Complete Arduino-based balance bot with source code, PID tuning videos, complementary filter, dead zone compensation. Closest pedagogical match.
   *What to look for:* Incremental commissioning methodology (IMU alone → motors alone → combine).

6. **B-ROBOT / JJRobots EVO 2**
   URL: `https://jjrobots.com/b-robot-evo-2/`
   *Relevance:* Open-source Arduino balance bot with cascade PD/PI control, dead zone handling, and anti-windup.
   *What to look for:* Control architecture and practical tuning approach.

### Embedded Firmware Patterns

7. **ArduinoMotorCarrier Library Source Code**
   URL: `https://github.com/arduino-libraries/ArduinoMotorCarrier`
   *Relevance:* Mandatory reading. Reveals I2C transaction timing, co-processor protocol, BNO055 data path.
   *What to look for:* What each API call does at the I2C level. Whether BNO055 is routed through ATSAMD11 or direct I2C.

8. **FreeRTOS-SAMD21 Port**
   URL: `https://github.com/BriscoeTech/Arduino-FreeRTOS-SAMD21`
   *Relevance:* Solves control loop vs. serial I/O vs. safety scheduling with proper task priorities.
   *What to look for:* Task creation, binary semaphores for ISR-to-task signaling, stack sizing for 32KB SRAM.

9. **SimpleFOC Library (Arduino-FOC)**
   URL: `https://github.com/simplefoc/Arduino-FOC`
   *Relevance:* Excellent firmware architecture patterns (timer ISR, sensor/controller/actuator separation, serial commander) transferable to BalanceBot.
   *What to look for:* Timer ISR structure, SAMD21-specific timer configuration, command interface pattern.

10. **Madgwick AHRS Filter**
    URL: `https://github.com/arduino-libraries/MadgwickAHRS`
    *Relevance:* Fallback if BNO055's internal fusion has too much latency. Lightweight quaternion-based filter.
    *What to look for:* Integration with raw accel+gyro data, beta parameter tuning.

### Sensor & Driver References

11. **BNO055 Datasheet + Application Note BST-BNO055-AN007**
    Search: `BNO055 "fusion output data rate" IMU mode vs NDOF mode`
    *Relevance:* IMU mode gives lowest latency. NDOF magnetometer recalibration causes transient jumps — catastrophic for balancing.
    *What to look for:* Section 3.6 (Output Data Rates), operation mode 0x08 (IMU mode).

12. **TI Application Note SLVA249 — "Current Limiting in H-Bridge Motor Drivers"**
    *Relevance:* Duty cycle clamp derivation from motor model, thermal protection for H-bridges.
    *What to look for:* Software current limiting methodology, thermal derating curves.

### Python Analysis Tools

13. **Python Control Systems Library (python-control)**
    URL: `https://python-control.readthedocs.io`
    *Relevance:* Python equivalent of MATLAB's Control System Toolbox. Bode plots, root locus, step response, sisotool.
    *What to look for:* `control.tf()`, `control.step_response()`, `control.bode_plot()`.

14. **SIPPY — System Identification Package for Python**
    URL: `https://github.com/CPCLAB-UNIPI/SIPPY`
    *Relevance:* Proper prediction-error system identification (ARX, ARMAX, state-space) from measured I/O data.
    *What to look for:* State-space identification from step response CSV data.

15. **Phil's Lab (YouTube) — Complementary Filter and PID Tuning**
    Search: `Phil's Lab complementary filter IMU PID`
    *Relevance:* Practical video tutorials bridging textbook theory and embedded implementation, with real hardware.
    *What to look for:* Complementary filter, anti-windup, visual tuning methodology.

16. **TinyMPC — Model Predictive Control for Microcontrollers**
    URL: `https://github.com/TinyMPC/TinyMPC`
    *Relevance:* Future path if progressing beyond LQR. Lightweight MPC for Cortex-M with balance system examples.
    *What to look for:* Fixed-size matrix operations, no dynamic allocation, deterministic iteration count.

---

## Dissent

### BNO055 fusion vs. custom complementary filter

- **Engineer:** Try BNO055 internal IMU mode fusion first, fall back to complementary filter only if latency is measured to be too high.
- **Embedded Developer:** More skeptical — data likely routes through ATSAMD11 (unknown latency), prefers Madgwick/Mahony on SAMD21 from raw sensor data for guaranteed low latency.
- **Chair's recommendation:** Characterize the BNO055 path first (latency measurement). If total sensor latency exceeds ~15ms, switch to complementary or Madgwick filter on SAMD21. Don't build the fallback until proven necessary.

### PID cascade vs. LQR state feedback

- **Engineer:** Recommends building the state-space model and designing LQR — naturally handles coupled angle-position dynamics.
- **Data Analyst / Embedded Developer:** Implicitly assume a PID cascade structure (inner angle, outer position).
- **Chair's recommendation:** Build the state-space model regardless. Start with PD tilt controller for initial balance proof-of-concept, then choose between cascade PID and LQR based on comfort level. Both work; LQR is theoretically cleaner, cascade PID is easier to tune incrementally.

---

## Recommended Next Steps

1. **Start with safety:** Implement the duty clamp (48%) and stall detection. 2-3 hours, protects hardware for all subsequent work.
2. **Characterize the unknowns:** Run the Motor Carrier timing test and BNO055 latency measurement. Determines whether the current software stack is viable for 100 Hz control.
3. **Build the model:** Measure CoG height, compute state-space matrices, verify open-loop eigenvalues. Unlocks principled controller design.
4. **Extend logging:** Add IMU angle and rate to CSV. Split the Python pipeline. Every experiment from this point captures the full state.

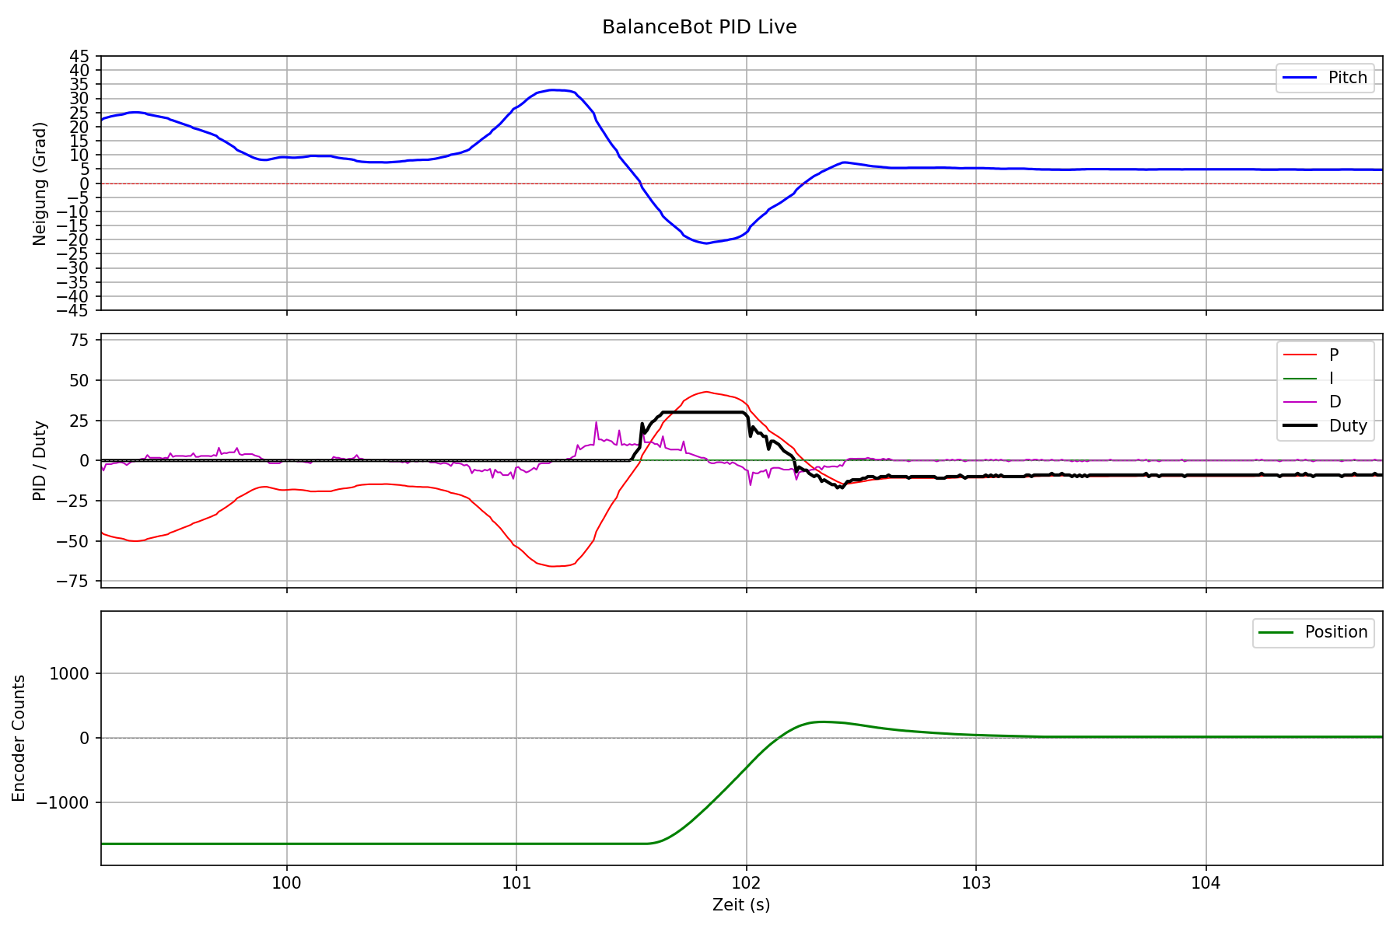
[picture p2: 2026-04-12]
Balancebot_code/messungen/pid_20260410_183701.png

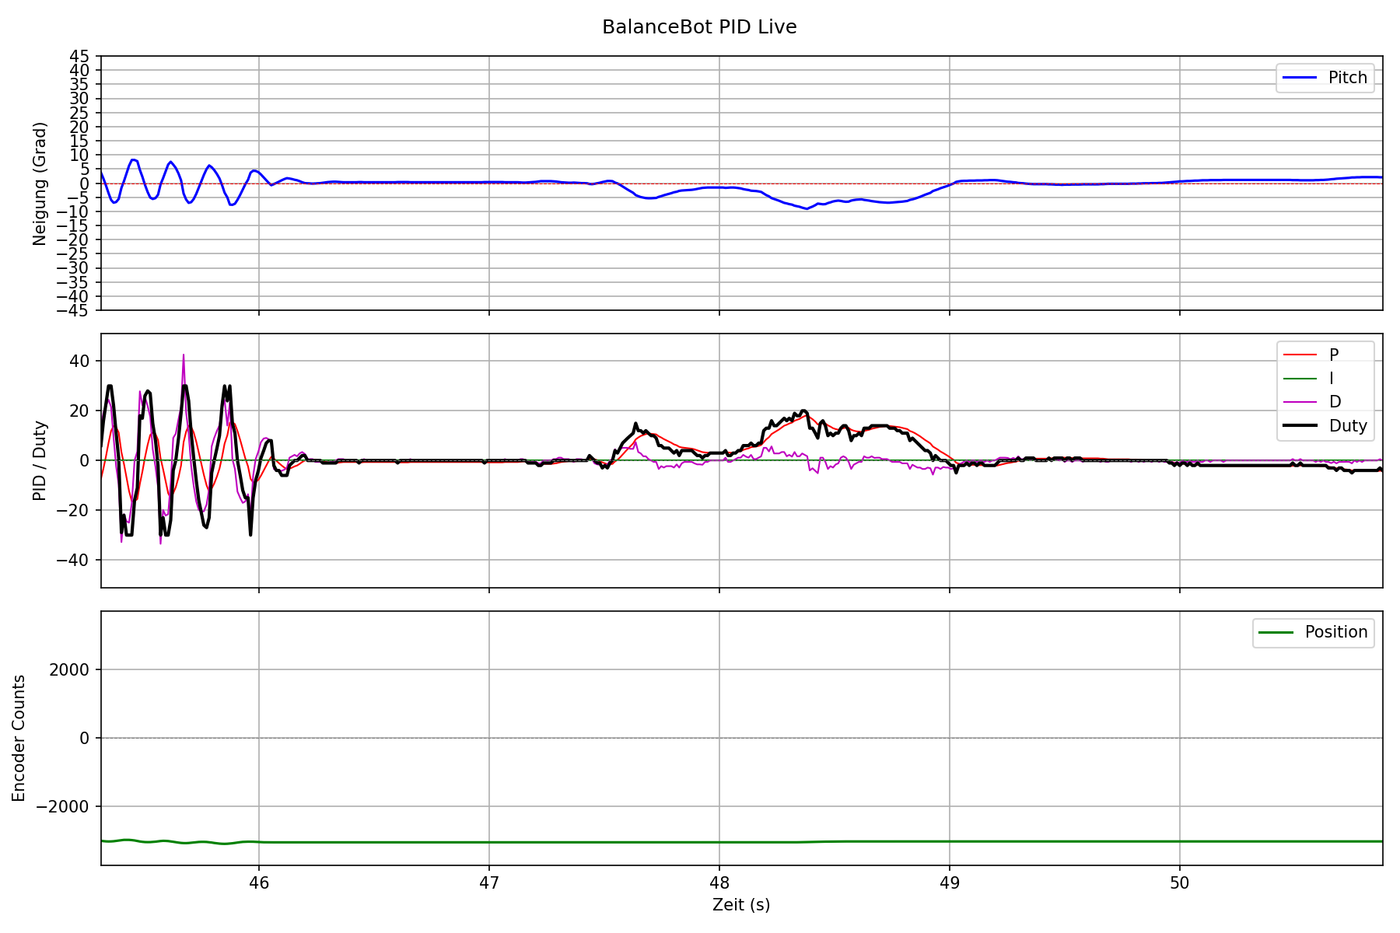
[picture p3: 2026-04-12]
Balancebot_code/messungen/pid_20260410_184142.png

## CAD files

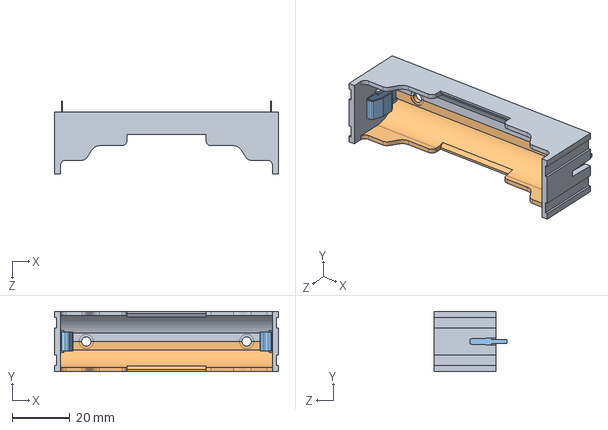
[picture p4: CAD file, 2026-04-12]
CAD_BalanceBot/User Library-18650 Full.STEP
77.6 x 20.8 x 25.5 mm
18650m_1
18650s_По умолчанию x 2

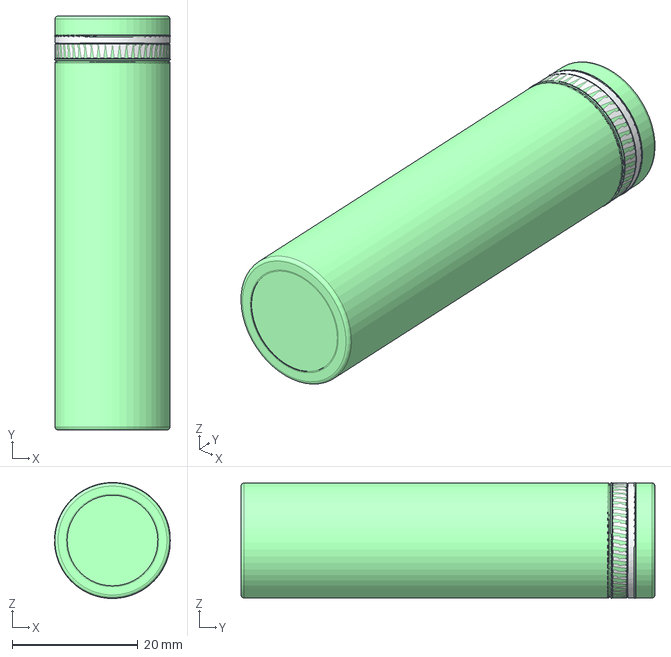
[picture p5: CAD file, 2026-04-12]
CAD_BalanceBot/Samsung INR18650-25R.stp
18.5 x 65.8 x 18.5 mm

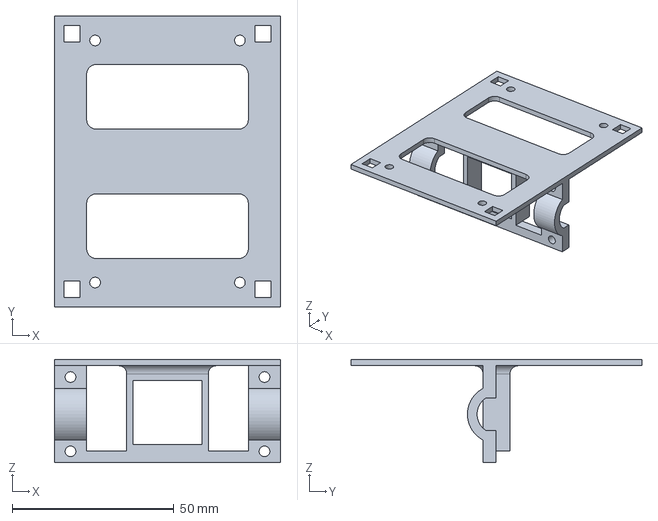
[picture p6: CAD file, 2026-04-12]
CAD_BalanceBot/botframe.FCStd
70.0 x 90.0 x 32.0 mm

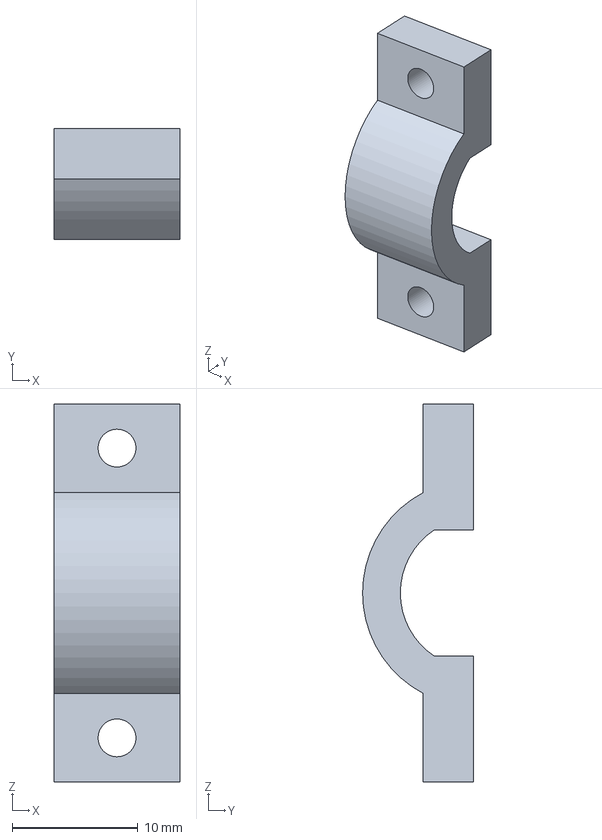
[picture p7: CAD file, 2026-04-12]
CAD_BalanceBot/motorhalter_lose.FCStd
10.0 x 8.80 x 30.0 mm

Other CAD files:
CAD_BalanceBot/Pololu_Wheel_90x10.FCStd
CAD_BalanceBot/Pololu 90mm Wheel.dwg

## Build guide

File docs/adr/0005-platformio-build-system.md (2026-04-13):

---
id: 0005
title: PlatformIO as the build and upload system
status: accepted
date: 2026-04-13
deciders: [both collaborators]
tags: [tooling, firmware, build]
---

# ADR-0005: PlatformIO as the build and upload system

## Context

Arduino firmware can be built and uploaded in several ways. The most
common starting point is the **Arduino IDE** — a graphical tool that
hides most of the build process. It works well for single-file sketches
but has significant limitations as a project grows:

- No support for a proper `src/` directory structure; all `.cpp` files
  must live in the sketch folder.
- Library management is global and per-machine, not per-project.
  Two collaborators can silently have different library versions installed.
- No CLI — building and uploading requires the GUI, making it harder
  to script or reproduce.
- No named build environments — switching between `balance_v1` and the
  modular `balance/` target, or between production firmware and test
  sketches, requires manual file swapping.

This project has five distinct firmware targets that need to coexist:
`balance_v1` (reference), `balance` (active development), and three
test sketches (`carrier_timing`, `imu_latency`, `deadzone_id`). Managing
these in the Arduino IDE would require five separate sketch folders with
duplicated library references.

## Decision

**PlatformIO** (`platformio.ini` at `Balancebot_code/`) is the build
and upload system for all firmware.

The configuration defines a shared `[common]` block (board, platform,
framework, baud rate, library dependencies) that all environments inherit.
Each environment overrides only `build_src_filter` to select its source:

| Environment | Source | Purpose |
|---|---|---|
| `balance_v1` | `src/balance.cpp` | Reference build — frozen |
| `balance` | `src/balance/` | Active modular firmware |
| `carrier_timing` | `src/tests/carrier_timing/` | Phase 1 test |
| `imu_latency` | `src/tests/imu_latency/` | Phase 2 test |
| `deadzone_id` | `src/tests/deadzone_id/` | Phase 3 test |

Library versions are pinned in `platformio.ini`:

```ini
lib_deps =
    adafruit/Adafruit BNO055@^1.6.1
    adafruit/Adafruit Unified Sensor@^1.1.14
    arduino-libraries/ArduinoMotorCarrier
```

Both collaborators build against the same versions regardless of what
is installed globally on their machines.

Common commands:
```bash
pio run -e balance -t upload   # build and flash active firmware
pio run -e balance_v1          # build reference (verify it still compiles)
pio device monitor             # open serial monitor at 115200 baud
```

## Consequences

**Positive**
- Library versions are locked in the repo. Both collaborators always
  build with identical dependencies.
- `build_src_filter` is the mechanism that enforces the firmware layout
  decision from ADR-0001: each environment compiles exactly one target,
  so `balance_v1` and `balance/` cannot accidentally include each other.
- Test sketches are first-class build targets — no file swapping needed
  to flash `carrier_timing` or `deadzone_id`.
- Builds and uploads are scriptable from the command line, which is
  required once we add CI or automated test runs.

**Negative**
- PlatformIO must be installed (`pip install platformio` or via the VS
  Code extension). A collaborator with only the Arduino IDE cannot build
  the project without installing it first.
- PlatformIO downloads board support packages and libraries on first
  use, which requires an internet connection and takes a few minutes.

**Neutral**
- The Arduino Nano 33 IoT board definition (`board = nano_33_iot`,
  `platform = atmelsam`) is specified once in `[common]` and inherited
  by all environments. Changing to a different board requires one line.

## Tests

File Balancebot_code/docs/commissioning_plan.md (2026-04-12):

# BalanceBot -- Inbetriebnahmeplan

**Prinzip:** Jede Phase erst abschließen bevor die nächste beginnt.  
**Sicherheit:** Bei jedem Motortest Räder in der Luft! Nur bei Phase 5+ frei stellen.

---

## Phase 0: Hardware-Verifikation (einmalig, ohne Code-Änderung)

Ziel: Sicherstellen dass alle Komponenten korrekt verdrahtet und funktionsfähig sind.

- [ ] Motor Carrier erkennt Arduino (rote LED blinkt, `controller.getFWVersion()` gibt Version aus)
- [ ] Beide Motoren laufen bei Duty=30 (motor_test → `pio run -e balance_v1 -t upload`)
- [ ] Beide Encoder zählen korrekt (encoder_test, Rad von Hand drehen)
- [ ] BNO055 liefert plausible Pitch-Werte (sensor_test, Bot kippen)
- [ ] Vorzeichen-Konventionen verifiziert (diagnose, siehe `docs/sign_conventions.md`)

---

## Phase 1: Motor Carrier Timing-Charakterisierung

Ziel: I2C-Timing aller API-Aufrufe messen.

```bash
pio run -e carrier_timing -t upload
python acquire.py --mode carrier
```

**Erfolgskriterium:** Summe aller Mean-Werte < 8000 µs (80% von 10 ms Budget)  
**Falls nicht erfüllt:** I2C-Takt erhöhen oder Aufrufe reduzieren

- [ ] `controller.ping()` latenz notiert: _______ µs
- [ ] `encoder1.getRawCount()` latenz: _______ µs
- [ ] `encoder2.getRawCount()` latenz: _______ µs
- [ ] `M1.setDuty()` latenz: _______ µs
- [ ] `bno.getEvent()` latenz (NDOF): _______ µs
- [ ] `bno.getEvent()` latenz (IMU-Modus): _______ µs
- [ ] Summe: _______ µs → Budget OK? ✓/✗

---

## Phase 2: BNO055 Modus-Entscheidung

Ziel: NDOF vs. IMU-Modus vergleichen, BNO055-Konfiguration festlegen.

```bash
pio run -e imu_latency -t upload
python acquire.py --mode imu > messungen/raw/imu_latency.csv
python analyze.py messungen/raw/imu_latency.csv --mode imu
```

**Entscheidungsregel:**
- Wenn `bno.getEvent()` Latenz < 5 ms **und** Kalibrierung stabil → NDOF-Modus OK
- Wenn Latenz > 5 ms **oder** Kalibrierungssprünge → IMU-Modus (0x08) verwenden
- Wenn IMU-Modus immer noch > 5 ms → Complementary Filter auf SAMD21 implementieren

- [ ] Entscheidung getroffen: _________________ (NDOF / IMU-Modus / Comp. Filter)
- [ ] `imu.cpp` entsprechend konfiguriert (TODO-Kommentar in imu.cpp)

---

## Phase 3: Totzone-Identifikation

Ziel: Minimal-Duty für Anlaufen beider Motoren messen.

```bash
pio run -e deadzone_id -t upload
python acquire.py --mode deadzone
python process.py messungen/raw/deadzone_*.csv --mode deadzone
python analyze.py messungen/processed/deadzone_*_proc.csv --mode deadzone
```

- [ ] Totzone M1 gemessen: _______ % Duty
- [ ] Totzone M2 gemessen: _______ % Duty
- [ ] `DEADZONE_DUTY` in `config.h` aktualisiert: _______

---

## Phase 4: CoG-Höhe messen (Knife-Edge-Test)

Ziel: Schwerpunkthöhe `COG_HEIGHT_M` für Systemmodell bestimmen.

**Methode:**
1. Bot auf eine schmale Kante (Lineal) legen
2. Kante verschieben bis Bot balanciert
3. Vertikalen Abstand der Kante von der Radachse messen
4. Das ist die CoG-Höhe über Achsmitte

- [ ] CoG-Höhe gemessen: _______ mm über Achsmitte
- [ ] `COG_HEIGHT_M` in `config.h` aktualisiert

---

## Phase 5: Systemmodell aufstellen

Ziel: Linearisiertes Zustandsraummodell des inversen Pendels.

Zustandsvektor: `[θ, θ̇, x, ẋ]` (Winkel, Winkelgeschwindigkeit, Position, Geschwindigkeit)

Referenz: Grasser et al. 2002 "JOE: A Mobile, Inverted Pendulum"

**Schritte:**
1. Motorparameter aus Datenblatt extrahieren (Ra ≈ 11.65 Ω, Kt aus Stallmoment)
2. Trägheitsmomente schätzen (Masse × CoG² als Näherung)
3. A- und B-Matrizen aufstellen
4. Eigenwerte des offenen Kreises berechnen (Python: `numpy.linalg.eig`)
5. Steuerbarkeit prüfen (Python: `control.ctrb`)

- [ ] A-Matrix aufgestellt
- [ ] B-Matrix aufgestellt
- [ ] Offene-Kreis-Eigenwerte: _________________ (unstabiler Pol erwartet!)
- [ ] System steuerbar: ✓/✗
- [ ] Dokumentation in `docs/system_model.md`

---

## Phase 6: Erster Balancierversuch (PD-Regler)

**NUR nach Abschluss von Phasen 0-4!**

Startkonfiguration in `config.h`:
```c
KP_ANGLE  = 2.0     // Startwert, aus Modell verfeinern
KI_ANGLE  = 0.0     // Ki=0 bis PD stabil!
KD_ANGLE  = 0.1     // Startwert
MAX_DUTY  = 30      // Konservativ beginnen, später auf 45 erhöhen
```

**Prozedur:**
1. Bot in der Hand halten
2. `balance`-Firmware flashen: `pio run -e balance -t upload`
3. Serial-Monitor öffnen: `pio device monitor`
4. Bot senkrecht halten, `s` eingeben (Start)
5. Sanft loslassen -- Bot sollte Korrekturkräfte spüren
6. Wenn Bot sofort wegfährt: Kp-Vorzeichen umkehren!
7. Logging starten: `python acquire.py`

**Tuning-Reihenfolge:**
1. Kp erhöhen bis Bot beginnt zu zittern, dann auf 70% reduzieren
2. Kd erhöhen bis Zittern verschwindet
3. Erst dann Ki vorsichtig einschalten (und Anti-Windup prüfen)

- [ ] PD-Regler balanciert stabil (ohne Drift-Korrektur)
- [ ] Ki eingeschaltet, Positionsdrift reduziert
- [ ] MAX_DUTY schrittweise auf 45 erhöht

---

## Phase 7: Positions-Außenregler

Ziel: Bot bleibt an einem Ort stehen.

- [ ] `KP_POS`, `KI_POS` in `config.h` gesetzt (nach PD-Phase)
- [ ] Positions-Regler in `main.cpp` aktiviert (TODO-Kommentar entfernen)
- [ ] Drift < 10 cm nach 30 Sekunden

---

## Messungen archivieren

Nach jedem Versuch:
```bash
python acquire.py                          # aufzeichnen
python process.py messungen/raw/*.csv      # verarbeiten
python analyze.py --save messungen/processed/*.csv  # Plots speichern
```

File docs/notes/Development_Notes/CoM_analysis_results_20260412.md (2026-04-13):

# BalanceBot Center of Mass Analysis

*Created: 12.04.2026 19:30:56*  
*Script: /home/phlix/workspaces/NewBalanceBot_planung/CAD_BalanceBot/CoM_analysis.py*

| Part | Vol [mm3] | Mass [g] | CoM X [mm] | CoM Y [mm] | CoM Z [mm] |
|---|---|---|---|---|---|
| botframe | 13592.7 | 14.14 | 0.00 | -0.78 | -5.17 |
| NANOMotorCarrier | 11434.0 | 21.15 | -0.22 | -4.38 | 4.58 |
| Arduino_Nano33IoT | 1530.2 | 2.83 | -0.02 | -0.50 | 12.89 |
| Battery_18650 | 8205.3 | 22.15 | -0.00 | 0.01 | -9.46 |
| motorhalter_R | 1187.7 | 1.24 | 30.00 | 3.79 | -15.00 |
| motorhalter_L | 1187.7 | 1.24 | -30.00 | 3.79 | -15.00 |
| N20_motor_R | 2838.3 | 12.77 | 29.56 | -0.58 | -13.82 |
| N20_motor_L | 2838.3 | 12.77 | -30.56 | -0.42 | -13.82 |
| Wheel_R_Hub | 10683.0 | 11.11 | 52.90 | -0.60 | -14.70 |
| Wheel_R_Tire | 19596.6 | 22.54 | 52.90 | -0.60 | -14.70 |
| Wheel_L_Hub | 10683.0 | 11.11 | -53.90 | -0.40 | -14.70 |
| Wheel_L_Tire | 19596.6 | 22.54 | -53.90 | -0.40 | -14.70 |
| CoM_Marker | 57.7 | 0.00 | -0.33 | -0.91 | -9.82 |
| **TOTAL** | **103431.3** | **155.58** | | | |

## Summary

| Metric | X [mm] | Y [mm] | Z [mm] |
|---|---|---|---|
| CoM (volume-weighted) | -0.35 | -0.83 | -10.45 |
| CoM (mass-weighted) | -0.33 | -0.91 | -9.82 |

- Wheel axle Z = -14.7 mm
- CoM height above axle: **4.88 mm** (mass-weighted)
- CoM Y offset from axle: **-0.91 mm** (positive = forward)

The coordinate origin is below the botframe base plate. Check the CAD-Assembly-File in FreeCAD to verify

For balancing: the CoM should be ABOVE the wheel axle (high Z) and centered on the axle in Y.

> CoM is **ABOVE** the axle (inverted pendulum, balanceable)

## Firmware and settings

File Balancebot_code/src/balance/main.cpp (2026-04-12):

// ============================================================
// main.cpp -- BalanceBot: Modulare Hauptschleife mit Zustandsmaschine
//
// Zustaende: INIT --> CALIBRATING --> IDLE --> BALANCING --> FALLEN --> E_STOP
//
// Serial-Befehle (ein Zeichen, Newline):
//   's'  --> IDLE nach BALANCING (start)
//   'q'  --> BALANCING nach IDLE (quit)
//   'r'  --> E_STOP nach INIT (reset, startet Initialisierung neu)
//   'h'  --> CSV-Header erneut ausgeben
//   'p'  --> Parameter ausgeben (Kp, Ki, Kd, Setpoint)
//
// TODO: Erweiterung um serielle Parameter-Aenderung (z.B. "Kp=3.5")
// ============================================================

#include <Arduino.h>
#include <SPI.h>
#include <ArduinoMotorCarrier.h>

#include "config.h"
#include "state_machine.h"
#include "imu.h"
#include "motor.h"
#include "encoder.h"
#include "pid.h"
#include "logger.h"

// ------------------------------------------------------------
// Globale Objekte
// ------------------------------------------------------------

Imu        imu;
MotorPair  motors;
Encoder    enc;

// Winkel-PID (innerer Regler)
Pid pidAngle(
    KP_ANGLE, KI_ANGLE, KD_ANGLE, KAW_ANGLE,
    INTEGRAL_MAX_ANGLE,
    -(float)MAX_DUTY, (float)MAX_DUTY
);

// Position-PID (aeusserer Regler -- erst nach stabilem Angle-PD aktivieren)
Pid pidPos(
    KP_POS, KI_POS, KD_POS, KAW_POS,
    20.0f, -MAX_POS_CORRECTION_DEG, MAX_POS_CORRECTION_DEG
);

// ------------------------------------------------------------
// Zustandsmaschine
// ------------------------------------------------------------

State        currentState = State::INIT;
unsigned long fallenStartMs = 0; // Zeitstempel des Eintritts in FALLEN

// Zustandswechsel mit Logging
void changeState(State next) {
    if (next == currentState) return;
    Logger::printStateChange(currentState, next);
    currentState = next;
}

// ------------------------------------------------------------
// Serial-Befehl lesen (non-blocking)
// Gibt '\0' zurueck wenn keine neuen Daten
// ------------------------------------------------------------

char readSerialCommand() {
    if (Serial.available() > 0) {
        return (char)Serial.read();
    }
    return '\0';
}

// ------------------------------------------------------------
// Parameter-Ausgabe fuer Debugging
// ------------------------------------------------------------

void printParams() {
    Logger::printComment("--- Parameter ---");
    Serial.print("# Kp=");  Serial.print(KP_ANGLE);
    Serial.print(" Ki=");   Serial.print(KI_ANGLE);
    Serial.print(" Kd=");   Serial.print(KD_ANGLE);
    Serial.print(" SP=");   Serial.println(SETPOINT_ANGLE_DEG);
    Serial.print("# MAX_DUTY="); Serial.println(MAX_DUTY);
}

// ------------------------------------------------------------
// Setup
// ------------------------------------------------------------

void setup() {
    Serial.begin(SERIAL_BAUD);
    while (!Serial) delay(10); // Auf Serial-Monitor warten

    Logger::printComment("BalanceBot startet...");

    // Motor Carrier initialisieren
    if (!controller.begin()) {
        Logger::printComment("FEHLER: Motor Carrier nicht gefunden!");
        changeState(State::E_STOP);
        return;
    }
    controller.reboot();
    delay(500);
    motors.begin();

    // IMU initialisieren
    if (!imu.begin()) {
        Logger::printComment("FEHLER: BNO055 nicht gefunden!");
        motors.stop();
        changeState(State::E_STOP);
        return;
    }

    // Initialisierung erfolgreich --> Kalibrierung starten
    changeState(State::CALIBRATING);
    Logger::printComment("Warte auf IMU-Kalibrierung... (Gyro und Accel Stufe 2)");
    Logger::printHeader();
}

// ------------------------------------------------------------
// Hauptschleife
// ------------------------------------------------------------

void loop() {
    // --- Timing ---
    static unsigned long prevMs = 0;
    unsigned long nowMs = millis();
    unsigned long elapsedMs = nowMs - prevMs;

    // Regelzyklus einhalten: nicht vor LOOP_PERIOD_MS
    if (elapsedMs < LOOP_PERIOD_MS) return;
    float dt = (float)elapsedMs / 1000.0f; // [s]
    prevMs = nowMs;

    // --- Serial-Befehle lesen ---
    char cmd = readSerialCommand();
    if (cmd == 'h') { Logger::printHeader(); }
    if (cmd == 'p') { printParams(); }

    // --- IMU immer lesen (fuer Sicherheitscheck) ---
    imu.update();
    float pitch = imu.pitch();

    // --- Encoder lesen ---
    enc.update(dt);

    // ============================================================
    // Zustandsmaschine
    // ============================================================
    switch (currentState) {

        // ---------------------------------------------------------
        case State::INIT:
            // Sollte nach setup() nicht mehr auftreten
            // Falls E_STOP --> INIT per 'r' Reset:
            if (cmd == 'r') {
                // Erneuter Initialisierungsversuch
                motors.stop();
                motors.resetStall();
                enc.reset();
                pidAngle.reset();
                pidPos.reset();
                if (controller.begin() && imu.begin()) {
                    changeState(State::CALIBRATING);
                } else {
                    Logger::printComment("FEHLER: Reset fehlgeschlagen");
                }
            }
            break;

        // ---------------------------------------------------------
        case State::CALIBRATING:
            // Warten bis IMU kalibriert ist
            if (imu.isCalibrated()) {
                Logger::printComment("IMU kalibriert. 's' druecken zum Starten.");
                changeState(State::IDLE);
            }
            // Sicherheit: auch bei Kalibrierung auf grossen Winkel reagieren
            if (abs(pitch) > FALLEN_ANGLE_DEG) {
                motors.stop();
                changeState(State::FALLEN);
            }
            break;

        // ---------------------------------------------------------
        case State::IDLE:
            motors.stop();

            if (cmd == 's') {
                // Startbefehl: PID zuruecksetzen und balancieren starten
                pidAngle.reset();
                pidPos.reset();
                enc.reset();
                motors.resetStall();
                if (abs(pitch) < RECOVERY_ANGLE_DEG) {
                    changeState(State::BALANCING);
                } else {
                    Logger::printComment("FEHLER: Zu grosser Startwinkel -- aufrecht hinstellen!");
                }
            }

            if (abs(pitch) > FALLEN_ANGLE_DEG) {
                changeState(State::FALLEN);
            }
            break;

        // ---------------------------------------------------------
        case State::BALANCING: {
            // --- Sicherheitscheck: Kippwinkel ---
            if (abs(pitch) > FALLEN_ANGLE_DEG) {
                motors.stop();
                changeState(State::FALLEN);
                break;
            }

            // --- Quit-Befehl ---
            if (cmd == 'q') {
                motors.stop();
                changeState(State::IDLE);
                break;
            }

            // --- Aeusserer Regler: Position --> Winkel-Sollwert ---
            // TODO: Positionsregler erst aktivieren wenn Winkelregler stabil ist!
            // Vorlaeufig: Winkel-Sollwert fix aus config.h
            float angleSp = SETPOINT_ANGLE_DEG;
            // Wenn Positionsregler aktiv (KP_POS > 0):
            // float posError = 0.0f - enc.positionM();  // Soll: an Ort bleiben
            // float posCorrection = pidPos.compute(posError, dt);
            // angleSp = SETPOINT_ANGLE_DEG + posCorrection;

            // --- Innerer Regler: Winkel --> Duty ---
            float angleError = angleSp - pitch;
            float duty_f     = pidAngle.compute(angleError, dt);
            int   duty       = (int)duty_f;

            // --- Motoren ansteuern ---
            motors.setDrive(duty);

            // --- Stall-Erkennung ---
            if (motors.checkStall(abs(enc.speedCps()))) {
                Logger::printComment("STALL erkannt --> E_STOP");
                motors.stop();
                changeState(State::E_STOP);
                break;
            }

            // --- Logging ---
            Logger::printData(
                nowMs,
                currentState,
                pitch,
                imu.pitchRate(),
                pidAngle.pTerm(),
                pidAngle.iTerm(),
                pidAngle.dTerm(),
                motors.lastDuty(),
                enc.position(),
                enc.positionM()
            );
            break;
        }

        // ---------------------------------------------------------
        case State::FALLEN:
            motors.stop();

            if (fallenStartMs == 0) {
                fallenStartMs = nowMs; // Eintrittszeit merken
            }

            // Warten bis Wartezeit abgelaufen und Bot aufgerichtet
            if ((nowMs - fallenStartMs) >= FALLEN_WAIT_MS) {
                if (abs(pitch) < RECOVERY_ANGLE_DEG) {
                    fallenStartMs = 0;
                    pidAngle.reset();
                    changeState(State::IDLE);
                }
            }
            break;

        // ---------------------------------------------------------
        case State::E_STOP:
            // Motoren AUS -- bleibt hier bis manueller Reset ('r')
            motors.stop();

            if (cmd == 'r') {
                changeState(State::INIT);
            }
            break;
    }
}

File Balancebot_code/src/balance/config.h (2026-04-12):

#pragma once

// ============================================================
// config.h -- BalanceBot: Alle konfigurierbaren Parameter
//
// Alle Tuning-Parameter, Schwellwerte und Systemkonstanten
// stehen hier zentral. Nichts davon soll im Steuercode
// als Magic Number auftauchen.
// ============================================================

// ------------------------------------------------------------
// Mechanik
// ------------------------------------------------------------

// Raddurchmesser [m]
constexpr float WHEEL_DIAMETER_M       = 0.090f;
// Radradius [m]
constexpr float WHEEL_RADIUS_M         = WHEEL_DIAMETER_M / 2.0f;
// Radumfang [m]
constexpr float WHEEL_CIRCUMFERENCE_M  = 3.14159265f * WHEEL_DIAMETER_M;

// Encoder-Ticks pro Radumdrehung (inkl. 100:1 Getriebe, Quadratur)
constexpr int   COUNTS_PER_WHEEL_REV   = 1200;
// Meter pro Count
constexpr float METERS_PER_COUNT       = WHEEL_CIRCUMFERENCE_M / COUNTS_PER_WHEEL_REV;

// Schwerpunkthöhe über Achsmitte [m]
// TODO: Durch Messung (Knife-Edge-Test) bestimmen!
// Vorlaeufige Schaetzung: Carrier bei ~75mm, Achse bei 45mm --> ~30mm
constexpr float COG_HEIGHT_M           = 0.030f;

// Gesamtmasse [kg]
constexpr float TOTAL_MASS_KG          = 0.204f;

// ------------------------------------------------------------
// Abtastzeit
// ------------------------------------------------------------

// Soll-Abtastzeit der Regelschleife [ms]
// 10 ms = 100 Hz. Nicht unter 10 ms gehen (Bandbreite des inversen Pendels)
constexpr unsigned long LOOP_PERIOD_MS = 10;

// ------------------------------------------------------------
// Motoren / Leistungselektronik
// ------------------------------------------------------------

// Maximaler Duty-Cycle [%]
// Motorstall: 1.03 A, Treibergrenze: 0.50 A
// 0.50 / 1.03 * 100 = 48.5 %  --> konservativ auf 45 % begrenzt
// Waehrend der ersten Inbetriebnahme: noch konservativer beginnen (z.B. 30)
constexpr int   MAX_DUTY               = 45;

// Mindest-Duty fuer Loslaufen (Totzone-Kompensation) [%]
// TODO: Durch deadzone_id-Test bestimmen!
constexpr int   DEADZONE_DUTY          = 10;

// Maximale Aenderung des Duty-Cycles pro Abtastschritt (Slew-Rate) [%/Schritt]
constexpr int   DUTY_SLEW_RATE         = 20;

// Stall-Erkennung:
// Wenn abs(duty) >= STALL_DUTY_THRESHOLD und abs(speed) <= STALL_SPEED_THRESHOLD
// fuer STALL_TIMEOUT_MS ms --> E_STOP ausloesen
constexpr int   STALL_DUTY_THRESHOLD   = 30;    // Duty-Wert ab dem Stall moeglich
constexpr int   STALL_SPEED_THRESHOLD  = 5;     // Encoder-Counts/s unter denen "zu langsam"
constexpr int   STALL_TIMEOUT_MS       = 500;   // Zeit bis Stall-E_STOP [ms]

// ------------------------------------------------------------
// Zustandsmaschine / Sicherheit
// ------------------------------------------------------------

// Sicherheits-Kippwinkel [Grad]
// Ueber diesem Winkel gilt der Bot als "gefallen" --> FALLEN-Zustand
constexpr float FALLEN_ANGLE_DEG       = 45.0f;

// Winkel fuer Rueckkehr aus FALLEN nach IDLE [Grad]
// Bot muss unter diesem Winkel stehen, bevor Motoren wieder aktiv werden
constexpr float RECOVERY_ANGLE_DEG     = 15.0f;

// Wartezeit nach FALLEN vor erneutem Versuch [ms]
constexpr unsigned long FALLEN_WAIT_MS = 1000;

// ------------------------------------------------------------
// PID-Winkelregler (innerer Regler)
// Stellt Kippwinkel auf Sollwert (0 Grad = aufrecht)
// ------------------------------------------------------------

// Proportionalverstaerkung
// TODO: Tuning -- Startpunkt aus Modell berechnen
constexpr float KP_ANGLE               = 2.0f;

// Integralverstaerkung
// Mit Ki=0 starten bis P+D stabil balanciert!
constexpr float KI_ANGLE               = 0.0f;

// Differentialverstaerkung
constexpr float KD_ANGLE               = 0.1f;

// Anti-Windup: Tracking-Verstaerkung (Rueckkopplung bei Saettigung)
// Kaw = 1/Ti = Ki/Kp (typischer Startwert)
// Nur aktiv wenn KI_ANGLE > 0
constexpr float KAW_ANGLE              = 0.1f;

// Integralbegrenzung [%] (als absoluter Wert des Integralbeitrags)
constexpr float INTEGRAL_MAX_ANGLE     = 20.0f;

// Winkel-Sollwert [Grad]
// Kann per Serial justiert werden um mechanischen Offset auszugleichen
constexpr float SETPOINT_ANGLE_DEG     = 0.0f;

// ------------------------------------------------------------
// PID-Positionsregler (aeusserer Regler -- spaetere Phase)
// Stellt Fahrzeugposition (Encoder-Summe) auf Sollwert
// ------------------------------------------------------------

constexpr float KP_POS                 = 0.0f;   // TODO: erst nach stabilem Angle-PD tunen
constexpr float KI_POS                 = 0.0f;
constexpr float KD_POS                 = 0.0f;
constexpr float KAW_POS                = 0.0f;

// Maximaler Positionsfehler der als Winkelkorrektur aufaddiert wird [Grad]
constexpr float MAX_POS_CORRECTION_DEG = 5.0f;

// ------------------------------------------------------------
// IMU
// ------------------------------------------------------------
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

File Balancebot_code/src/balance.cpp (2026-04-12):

// ============================================================
// BalanceBot - PID-Regler (Neustart)
//
// Verifizierte Fakten aus Diagnose:
//   - Setpoint = 0 Grad
//   - Vorwaerts kippen = negativer Pitch
//   - Vorwaerts fahren: M1(-), M2(+), Enc1 negativ, Enc2 positiv
//   - Encoder-Limit: max 1 Umdrehung (verhindert Wegfahren)
//
// Serial: millis,pitch,p,i,d,pid_out,duty,position
// ============================================================

#include <Arduino.h>
#include <SPI.h>
#include <ArduinoMotorCarrier.h>
#include <Wire.h>
#include <Adafruit_Sensor.h>
#include <Adafruit_BNO055.h>

Adafruit_BNO055 bno = Adafruit_BNO055(55, 0x28);

// ============================================================
// PID-Parameter (hier tunen!)
// ============================================================
float Kp = 2.0;
float Ki = 0.0;
float Kd = 0.1;
float setpoint = 0.0;

// --- Grenzen ---
const int MAX_DUTY = 30;
const float SICHERHEITS_WINKEL = 45.0;
const float INTEGRAL_MAX = 50.0;

// --- Encoder-Limit ---
// Counts fuer 1 Umdrehung. Falls unbekannt: Rad von Hand drehen,
// Wert im Live-Plot ablesen, hier eintragen.
const int COUNTS_PRO_UMDREHUNG = 1200;

// --- PID-Zustand ---
float fehler_vorher = 0.0;
float integral = 0.0;
unsigned long zeit_vorher = 0;
bool erster_durchlauf = true;

void setup() {
    Serial.begin(115200);
    while (!Serial) delay(10);

    Serial.println("=== BalanceBot PID ===");

    if (!bno.begin()) {
        Serial.println("BNO055 FEHLER");
        while (1) delay(100);
    }
    bno.setExtCrystalUse(true);

    if (!controller.begin()) {
        Serial.println("Motor Carrier FEHLER");
        while (1) delay(100);
    }
    controller.reboot();
    delay(500);

    M1.setDuty(0);
    M2.setDuty(0);
    encoder1.resetCounter(0);
    encoder2.resetCounter(0);

    Serial.println("millis,pitch,p,i,d,duty,position");
    delay(2000);
    zeit_vorher = millis();
}

void loop() {
    // --- Sensor lesen (kein Filter, BNO055 hat eigene Fusion) ---
    sensors_event_t event;
    bno.getEvent(&event);
    float pitch = event.orientation.z;

    // --- Sicherheit ---
    if (abs(pitch - setpoint) > SICHERHEITS_WINKEL) {
        M1.setDuty(0);
        M2.setDuty(0);
        controller.ping();
        integral = 0.0;
        fehler_vorher = 0.0;
        erster_durchlauf = true;
        zeit_vorher = millis();
        encoder1.resetCounter(0);
        encoder2.resetCounter(0);
        delay(500);
        return;
    }

    // --- Zeit ---
    unsigned long jetzt = millis();
    float dt = (jetzt - zeit_vorher) / 1000.0;
    if (dt < 0.01) return;  // Min 10ms zwischen Zyklen (100 Hz, nicht-blockierend)

    // --- PID ---
    float fehler = setpoint - pitch;

    float p = Kp * fehler;

    integral += fehler * dt;
    if (integral > INTEGRAL_MAX) integral = INTEGRAL_MAX;
    if (integral < -INTEGRAL_MAX) integral = -INTEGRAL_MAX;
    float i = Ki * integral;

    float d = 0.0;
    if (erster_durchlauf) {
        erster_durchlauf = false;
    } else {
        d = Kd * ((fehler - fehler_vorher) / dt);
    }

    float pid_out = p + i + d;

    // --- Duty begrenzen ---
    int duty = (int)pid_out;
    if (duty > MAX_DUTY) duty = MAX_DUTY;
    if (duty < -MAX_DUTY) duty = -MAX_DUTY;

    // --- Encoder-Position ---
    int pos1 = encoder1.getRawCount();
    int pos2 = encoder2.getRawCount();
    float position = (float)(pos2 - pos1) / 2.0;

    // --- Encoder-Limit: max 1 Umdrehung ---
    //if (position > COUNTS_PRO_UMDREHUNG && duty > 0) duty = 0;
    //if (position < -COUNTS_PRO_UMDREHUNG && duty < 0) duty = 0;

    // --- Motoren ---
    M1.setDuty(-duty);
    M2.setDuty(duty);
    controller.ping();

    // --- Serial CSV ---
    Serial.print(jetzt);
    Serial.print(",");
    Serial.print(pitch, 2);
    Serial.print(",");
    Serial.print(p, 2);
    Serial.print(",");
    Serial.print(i, 2);
    Serial.print(",");
    Serial.print(d, 2);
    Serial.print(",");
    Serial.print(duty);
    Serial.print(",");
    Serial.println((int)position);

    fehler_vorher = fehler;
    zeit_vorher = jetzt;
}

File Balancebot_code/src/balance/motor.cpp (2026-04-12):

// ============================================================
// motor.cpp -- BalanceBot: Motor-Implementierung
// ============================================================

#include "motor.h"
#include "config.h"
#include <ArduinoMotorCarrier.h>

void MotorPair::begin() {
    // Startposition: beide Motoren aus
    M1.setDuty(0);
    M2.setDuty(0);
    _lastDuty = 0;
    resetStall();
}

void MotorPair::setDrive(int duty) {
    // --- Slew-Rate-Begrenzung ---
    // Duty darf sich pro Schritt hoechstens um DUTY_SLEW_RATE aendern.
    // Verhindert Strom-Spikes bei abrupten Richtungswechseln.
    int delta = duty - _lastDuty;
    if (delta >  DUTY_SLEW_RATE) duty = _lastDuty + DUTY_SLEW_RATE;
    if (delta < -DUTY_SLEW_RATE) duty = _lastDuty - DUTY_SLEW_RATE;

    // --- Absolute Begrenzung (Treiberschutz) ---
    // MAX_DUTY ist so gewaehlt, dass Stallstrom unter Treibergrenze bleibt
    if (duty >  MAX_DUTY) duty =  MAX_DUTY;
    if (duty < -MAX_DUTY) duty = -MAX_DUTY;

    _lastDuty = duty;
    _applyToMotors(duty);
}

void MotorPair::stop() {
    // Sofortiger Stop ohne Slew-Rate (fuer Sicherheitszustaende)
    _lastDuty = 0;
    M1.setDuty(0);
    M2.setDuty(0);
    controller.ping(); // Watchdog-Ping benoetigt
}

void MotorPair::_applyToMotors(int duty) {
    // Totzonenkompensation:
    // Duty-Werte unterhalb der Totzone werden auf 0 gesetzt,
    // da die Motoren sonst nicht anlaufen wuerden.
    // TODO: Totzonen pro Motor separat messen (deadzone_id-Sketch)!
    int m1Duty, m2Duty;
    if (duty == 0) {
        // Explizit stoppen
        m1Duty = 0;
        m2Duty = 0;
    } else if (abs(duty) < DEADZONE_DUTY) {
        // Zu schwaches Signal -- auf Totzonenrand hochsetzen
        int sign = (duty > 0) ? 1 : -1;
        m1Duty = -sign * DEADZONE_DUTY; // M1 dreht invertiert (Einbaulage)
        m2Duty =  sign * DEADZONE_DUTY;
    } else {
        // Normale Ansteuerung
        // Vorwaerts (duty > 0): M1 bekommt negatives Signal (Einbaulage rechte Seite)
        m1Duty = -duty;
        m2Duty =  duty;
    }

    M1.setDuty(m1Duty);
    M2.setDuty(m2Duty);
    controller.ping(); // Motor Carrier Watchdog-Ping (benoetigt ca. alle 100ms)
}

bool MotorPair::checkStall(int encoderSpeedCps) {
    // Stall-Bedingung: hoher Duty bei zu geringer Encoder-Geschwindigkeit
    bool condition = (abs(_lastDuty) >= STALL_DUTY_THRESHOLD) &&
                     (encoderSpeedCps <= STALL_SPEED_THRESHOLD);

    if (condition) {
        if (!_stallActive) {
            // Stall-Bedingung beginnt gerade -- Startzeit merken
            _stallActive  = true;
            _stallStartMs = millis();
        }
        // Stall-Timeout pruefen
        if ((millis() - _stallStartMs) >= (unsigned long)STALL_TIMEOUT_MS) {
            return true; // Stall bestaetigt --> E_STOP ausloesen
        }
    } else {
        // Bedingung nicht mehr erfuellt -- Zaehler zuruecksetzen
        _stallActive = false;
    }

    return false; // Kein Stall
}

void MotorPair::resetStall() {
    _stallActive  = false;
    _stallStartMs = 0;
}

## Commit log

2026-04-12 Fix CAD assambly. add archiv
    [Pololu_Wheel_90x10.FCStd]
2026-04-12 docs: add ADR-0003 motor duty cycle hard-capped at 45%
2026-04-12 docs: add ADR-0004 three-stage Python pipeline supersedes standalone scripts
2026-04-13 docs: add ADR-0006 control loop period fixed at 10ms (100 Hz)
2026-04-13 chore: add pyproject.toml with Python version pin and ruff linter (#4)
2026-04-13 feat: update CoM analysis and assembly (#7)
    feat: update CoM analysis, add cog_erklaerung
    [botframe.FCStd, carrierV4.FCStd]
2026-04-13 docs: add README, knowledge base, and documentation style (#16)
    * chore: add Knowledg and Notes folders
    * docs: add omega_0 derivation, Steiner proof, and parameter tables to CoM doc
    Add full derivation of inverted pendulum angular frequency and
    Steiner's parallel axis theorem to Schwerpunkt_des_Balancebot_erklaerung.md.
    All formulas now include parameter tables with SI units.
    Add documentation style rule for formulas to CLAUDE.md.
    Fix typo in filename (Scherpunkt -> Schwerpunkt).
    * docs: add README, move Knowledg and Notes into docs/
    - Add README.md with project overview, hardware specs, commissioning
    phases, and CAD assembly image
    - Move Knowledg/ → docs/knowledg/ and Notes/ → do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
